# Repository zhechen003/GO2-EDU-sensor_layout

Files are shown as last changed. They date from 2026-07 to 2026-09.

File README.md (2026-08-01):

# GO2 EDU Sensor Layout & Quick-Release Mounting Kit

<p align="center">
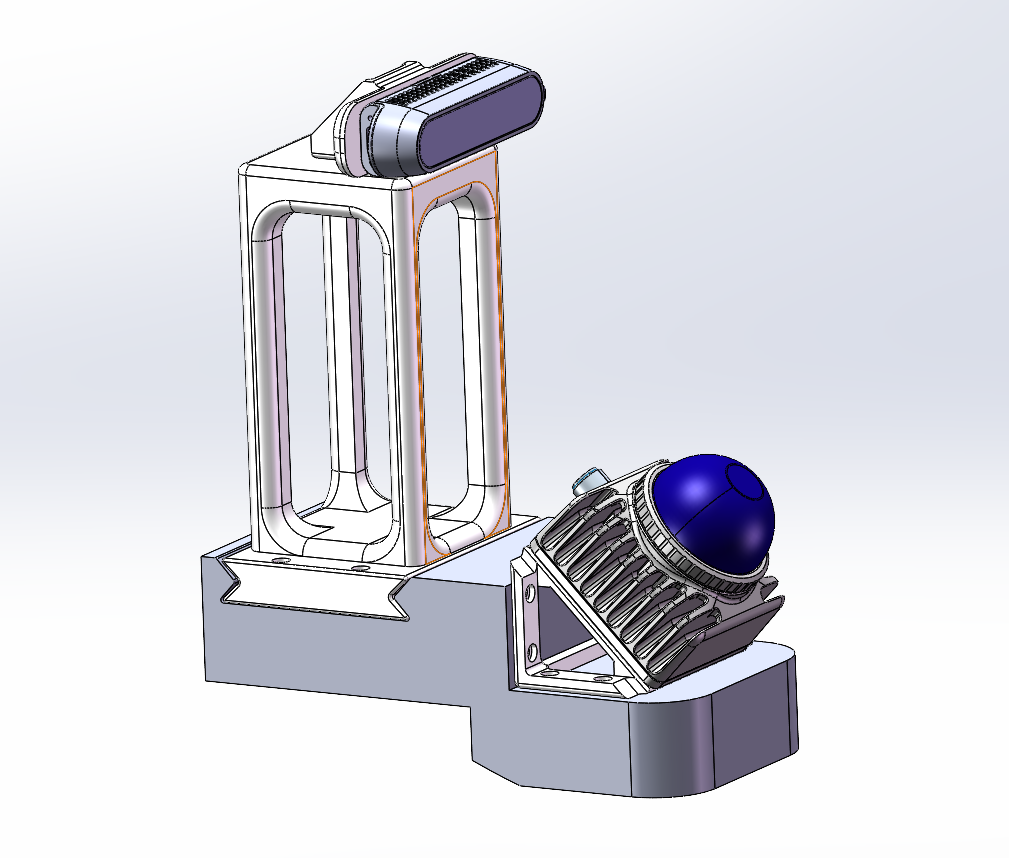
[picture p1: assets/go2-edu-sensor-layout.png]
GO2 EDU RealSense and Mid-360 sensor layout
  
</p>

<p align="center">
  <strong>English</strong> · <a href="README_CN.md">中文</a>
</p>

This repository contains a modular 3D sensor-layout and mounting kit for the **Unitree GO2 EDU**. It integrates an **Intel RealSense depth camera** and a **Livox Mid-360 LiDAR** into a compact head-mounted assembly.

The design separates the camera mount, LiDAR mount, quick-release adapter, and GO2 EDU mounting structure so that sensing hardware can be installed, removed, and reconfigured quickly for development, transport, or different payload setups.

> 中文说明请参阅 [README_CN.md](README_CN.md)。

## Highlights

- **Dual-sensor integration** — Dedicated mounting points for a RealSense depth camera and a Mid-360 LiDAR.
- **3D perception-oriented layout** — Designed to account for camera field of view, LiDAR coverage, and clearance from the robot body.
- **Modular architecture** — Individual camera, LiDAR, head-mount, and adapter components can be serviced or replaced independently.
- **Quick-release workflow** — Uses a quick-release adapter for fast installation and removal during testing, transport, and payload changes.
- **Manufacturing-ready assets** — Includes SolidWorks source parts, STL files for 3D printing, and a STEP exchange file.

## Repository Contents

| File | Description |
| --- | --- |
| `Go2EDU-head.SLDPRT` / `Go2EDU-head.STL` | GO2 EDU head / primary mounting structure |
| `camera_support.SLDPRT` / `camera_support.STL` | Camera support structure |
| `realsense_support.SLDPRT` / `realsense_support.STL` | RealSense camera mounting part |
| `lidarsupport1.SLDPRT` / `lidarsupport1.STL` | Mid-360 LiDAR mounting bracket |
| `arc-swiss.SLDPRT` / `arc-swiss.STL` | Quick-release adapter |
| `backborad1.SLDPRT` / `backborad1.STEP` | Rear connection / mounting plate |

## Installation Overview

1. Secure `Go2EDU-head` to the intended GO2 EDU mounting location.
2. Attach and lock the `arc-swiss` quick-release adapter.
3. Fit `realsense_support` and `lidarsupport1` to their respective mounting positions.
4. Install the RealSense camera and Mid-360 LiDAR, then verify that brackets, cables, and the robot body do not obstruct their fields of view.
5. Route and secure all sensor cables with enough slack to prevent interference during robot motion.

## Assembly Hardware List

| Feature / Location | Hardware | Quantity / Usage |
| --- | --- | --- |
| 4 mm holes | M3×5 土八 heat-set inserts | 19 pcs |
| 3.2 mm holes | M3×8 screws | 10 pcs |
| 3.2 mm holes | M3×15 screws | 8 pcs |
| Rear plate | M3×85 screws | 4 pcs, for rear plate fixation |
| Rear-plate rail | Black long screws | For the four front dog-head fixation points |

Install the heat-set inserts in the 4 mm holes and use the M3 screws in the 3.2 mm holes as indicated above. Verify the actual screw length and thread engagement before final tightening.

## Used in Research Projects

This sensor configuration has been used in the following GO2 research systems:

- **[SCAN-Planner](https://github.com/wuyi2121/SCAN-Planner)** — *Spatial Collision-Aware Local Planning for Route-Guided Long-Range Quadruped Navigation*. [Paper (arXiv:2606.19555)](https://arxiv.org/abs/2606.19555)
- **[TravExplorer](https://github.com/wuyi2121/TravExplorer)** — *Cross-Floor Embodied Exploration via Traversability-Aware 3D Planning*. [Paper (arXiv:2605.19958)](https://arxiv.org/abs/2605.19958)

## Manufacturing and Editing

- Use the `.STL` files for 3D-printing trials.
- Edit the `.SLDPRT` source files in SolidWorks to adapt dimensions or interfaces.
- Use `backborad1.STEP` to exchange the rear plate with other CAD tools or assemblies.

## Author and License

Maintained by [zhechen003](https://github.com/zhechen003).

The hardware design files in this repository are licensed under the
[CERN Open Hardware Licence Version 2 – Permissive](LICENSE).

Copyright (c) 2026 zhechen003.

## Safety and Compatibility

Before operating the robot, inspect fasteners, cable routing, payload balance, and sensor visibility. Confirm all mechanical dimensions, fastener specifications, cable routing, and electrical interfaces against the exact GO2 EDU, RealSense, and Mid-360 hardware in use.

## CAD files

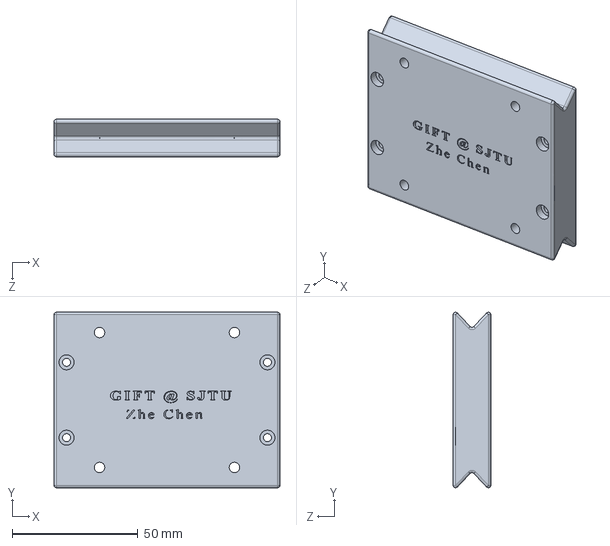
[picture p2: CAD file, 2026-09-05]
arc-swiss.SLDPRT
90.0 x 69.9 x 15.0 mm

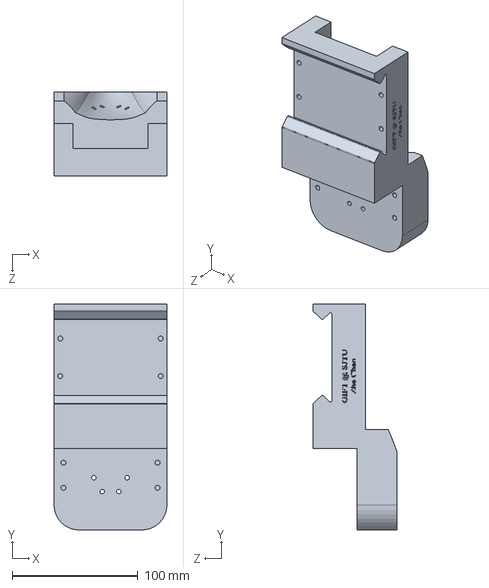
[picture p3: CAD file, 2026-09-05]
Go2EDU-head.SLDPRT
90.0 x 180.0 x 67.0 mm

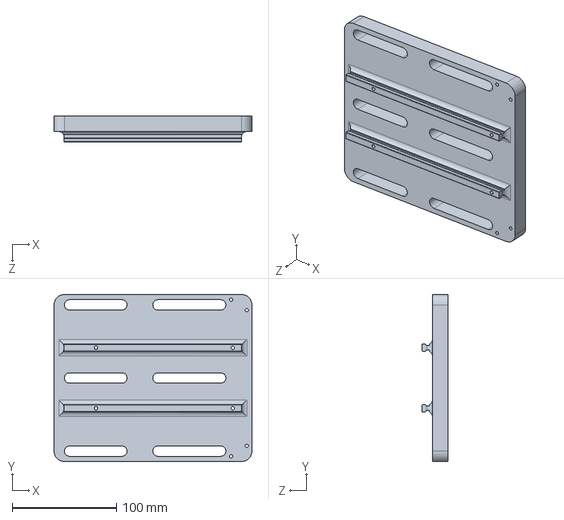
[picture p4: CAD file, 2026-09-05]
backborad1_short.SLDPRT
189.6 x 160.0 x 25.0 mm

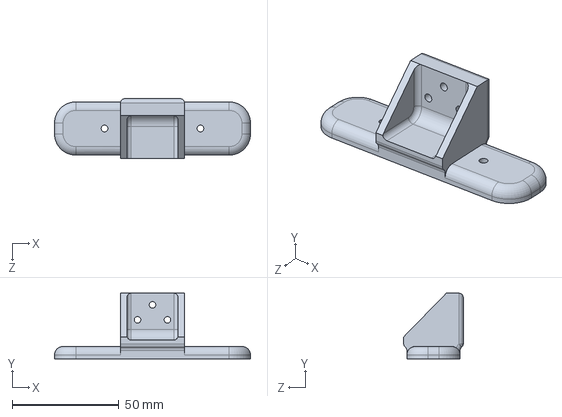
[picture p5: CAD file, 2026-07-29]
realsense_support.SLDPRT
92.0 x 30.8 x 28.0 mm

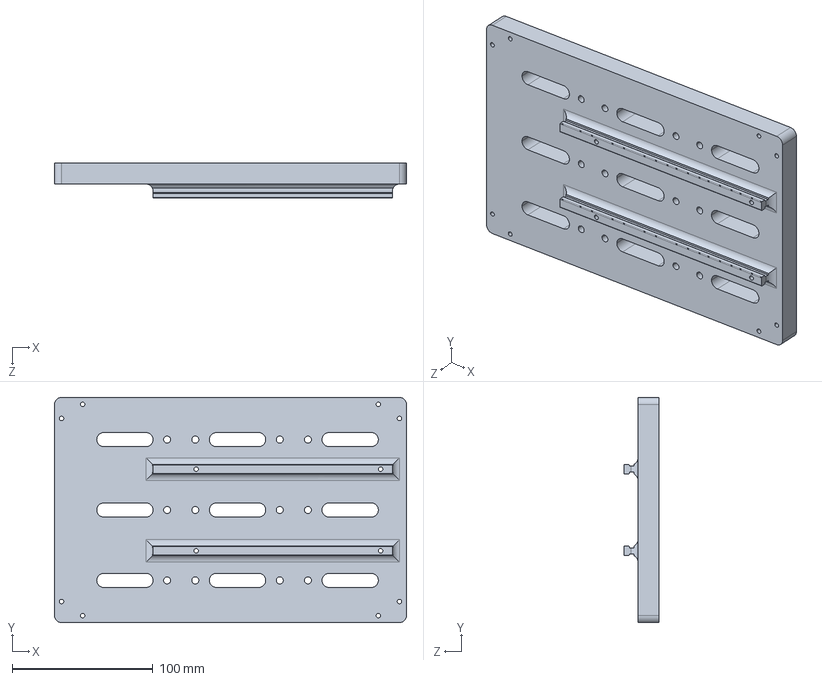
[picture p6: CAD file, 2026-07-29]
backborad1.STEP
250.0 x 160.0 x 25.0 mm

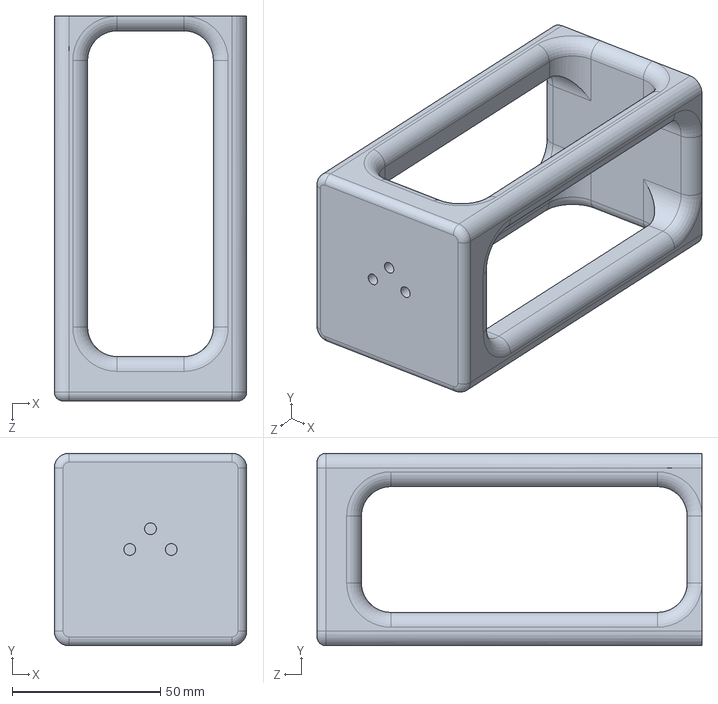
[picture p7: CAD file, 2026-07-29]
camera_support.SLDPRT
65.0 x 65.0 x 130.0 mm

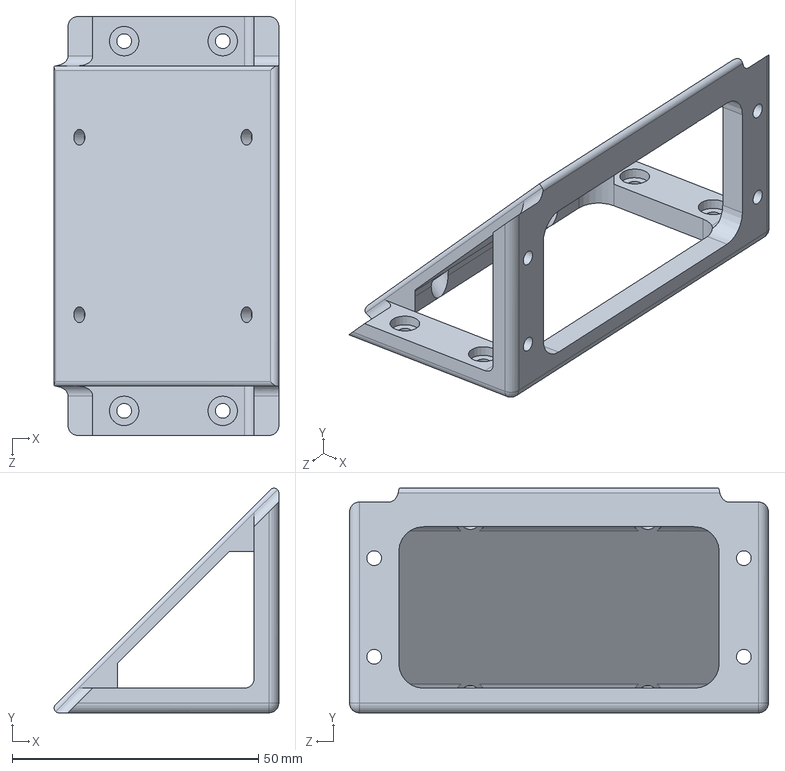
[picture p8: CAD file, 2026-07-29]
lidarsupport1.SLDPRT
45.6 x 45.6 x 85.0 mm

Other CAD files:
Go2EDU-head.STL
arc-swiss.STL
backborad1.SLDPRT
backborad1_short.STL
camera_support.STL
lidarsupport1.STL
realsense_support.STL

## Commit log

2026-07-29 Add GO2 EDU sensor layout README
2026-07-29 Add GO2 EDU sensor layout CAD models
    [Go2EDU-head.SLDPRT, Go2EDU-head.STL, arc-swiss.SLDPRT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]
2026-07-29 Fix uploaded file integrity
    [Go2EDU-head.SLDPRT]
2026-08-01 docs: add assembly hardware list
2026-08-02 short backboard
    [backborad1_short.SLDPRT, backborad1_short.STL]
2026-09-05 Update sensor mounting CAD models
    [Go2EDU-head.SLDPRT, Go2EDU-head.STL, arc-swiss.SLDPRT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]
